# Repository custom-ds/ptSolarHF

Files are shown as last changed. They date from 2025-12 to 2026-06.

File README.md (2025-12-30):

# ptSolarHF
The ptSolar is the newest version of Project: Traveler's series of APRS trackers. The ptSolar has been designed and optimized for low-power operation, especially when using a solar panel.

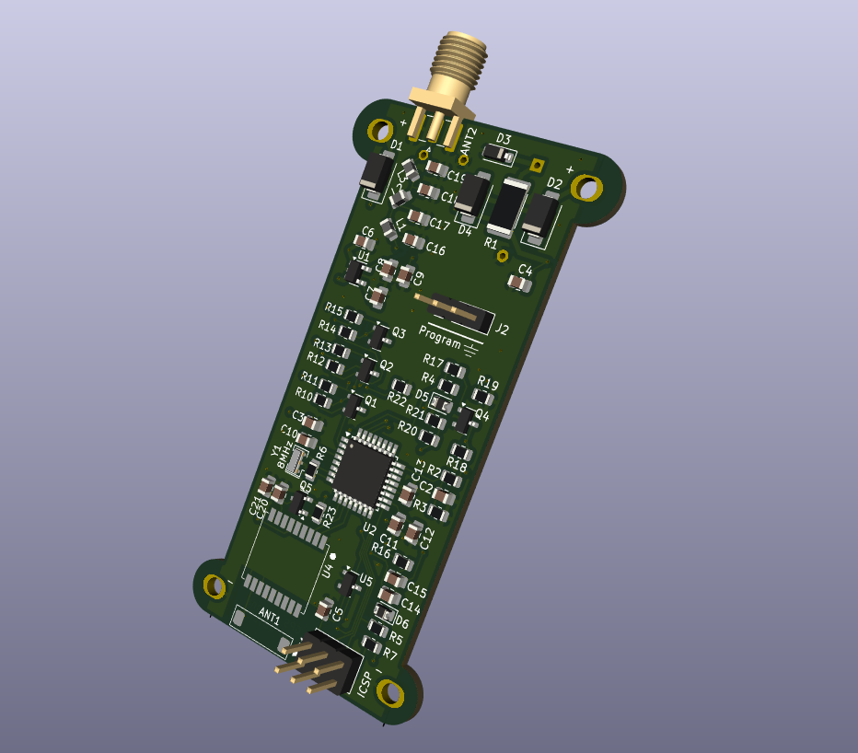
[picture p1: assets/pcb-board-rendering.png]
3D rendering of the ptSolar circuit board.


Under the hood, the ptSolar runs on the same __Microchip ATMega328p__ microcontroller that the other trackers have been using for years, although this board runs at a lower 3.3 volt level, and a slower 8MHz clock speed.

A 2m VHF transmitter is provided by the __SA818S-V__ transmitter-on-a-chip system, which means it's frequency agile and can be used throughout the world.

The GPS receiver is utilizes the __ATGM336H__ GPS engine which has a light-weight footprint while being a cost-effective solution. The ATGM336H is capable of position reports in excess of 60,000', making it a suitable solution for high altitude (latex) balloons traveling to over 100,000'.

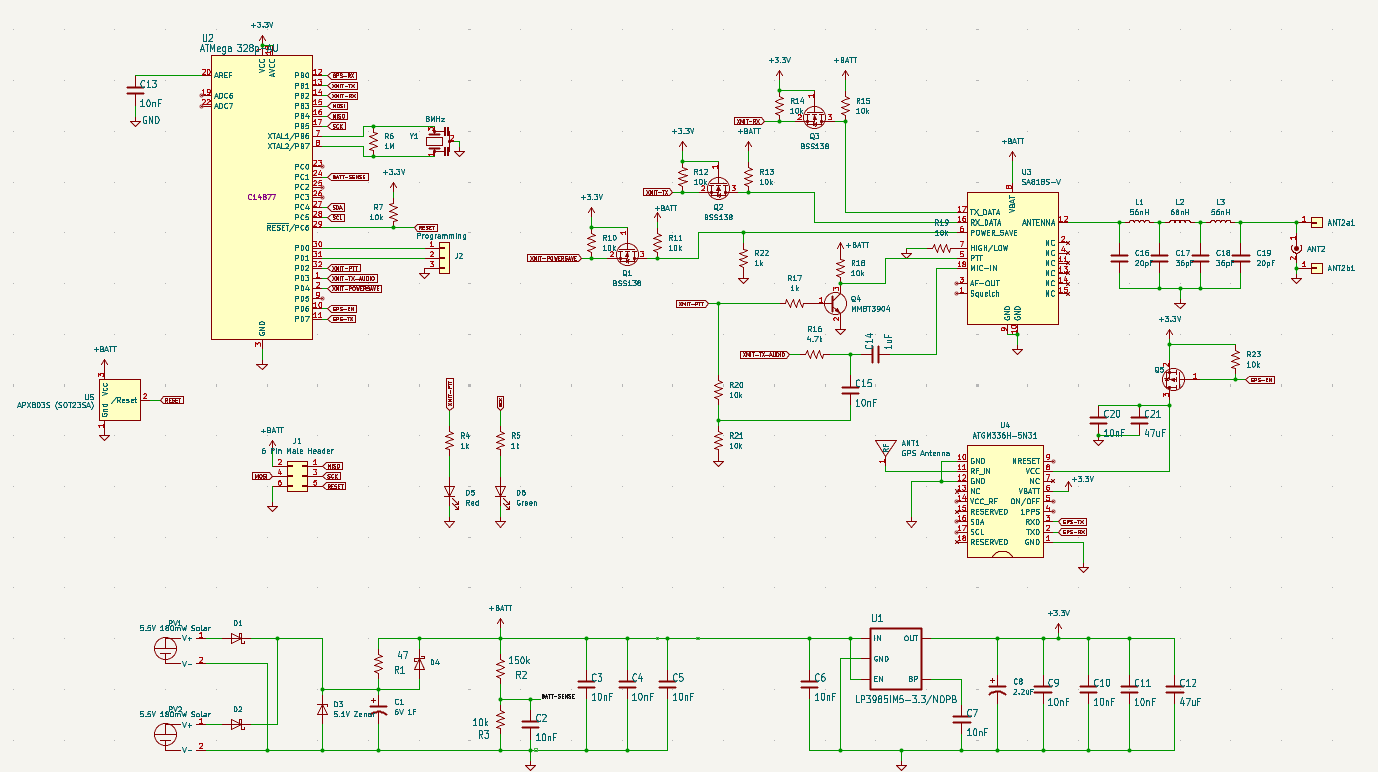
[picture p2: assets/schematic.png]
ptSolar schematic diagram.


## The Circuit Board
The circuit board is designed in Kicad and features a 4-layer design with castellated solder points for the attached solar panels.

The ptSolar is currently in the prototyping stages. Version 1.1.0 of the PCB was the initial design that was first built in early 2025, and includes the ATMega328p microcontroller, an ATGM336H GPS receiver, and the SA818S-V VHF transmitter. VHF signal filtering is provided by a 3-pole pi filter, reducing spurious harmonic output to well within Part 97 specifications.

## The Breakout Board
A Breakout board has been developed that can be temporarily or permanently paired to the top of the ptSolar tracker. The breakout includes a second ISCP programming port, a second serial data interface for configuring the tracker, a Sparkfun Qwiic connector for interfacing with other I2C sensors.

There is also a 2.1mm barrel jack for accepting power from a battery pack, along with the required 5V regulator when operating at higher supplied voltages. 

The Breakout Board mates to the tracker with a female .1" header connecting into the 6-pin (ISCP) and 8-pin (Serial, I2C) plugs on the ptSolar.

## Preparing the IDE for the Firmware
In the Arduino IDE and go to File &rarr; Preferences.  In the Additional Boards Manager URLs field, add the URL to the Project: Traveler website .json file:

```
https://www.projecttraveler.org/downloads/package_projecttraveler_index.json
```

Note that if there's already something in that field, you can click the small icon to the right of the text field where you are allowed to enter multiple entries on multiple lines.

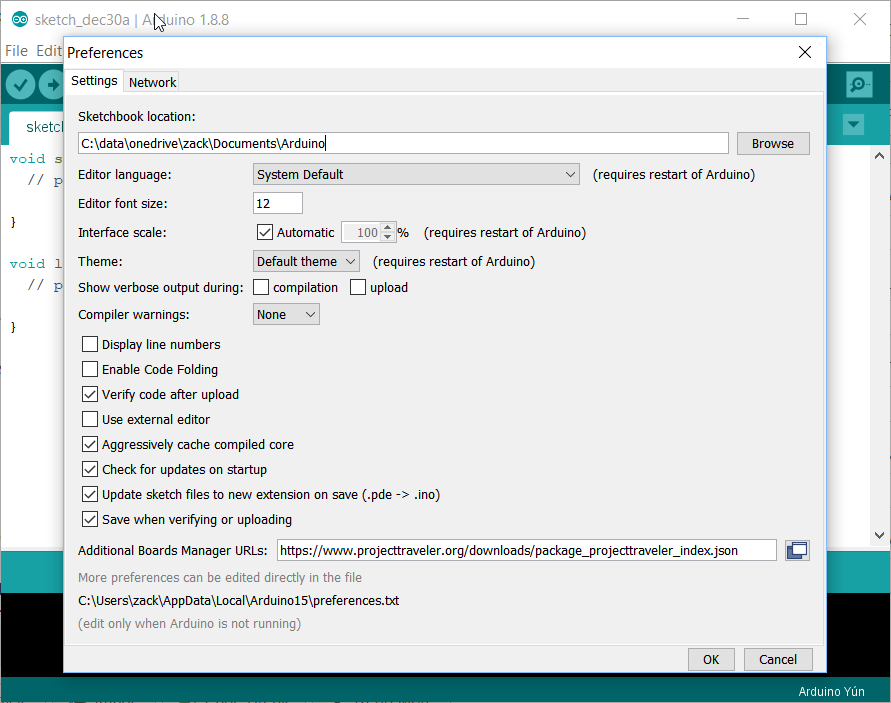
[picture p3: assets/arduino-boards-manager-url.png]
Setting the custom download URL for the Boards Manager.


Click OK to close the preferences dialog.  Then go to Tools &rarr; Boards &rarr; Boards Manager.

When the Boards Manager opens, select "Contributed" from the Type drop-down.  In the resulting list, you should find the Project Traveler Boards by Project Traveler option.  Click the Install button in the lower-right corner.

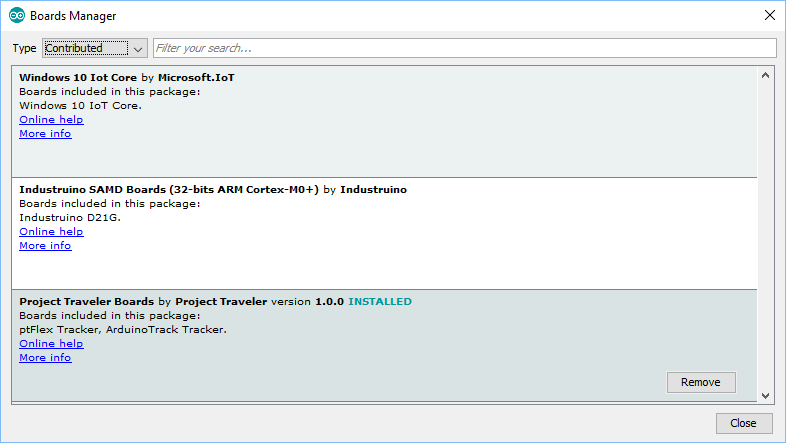
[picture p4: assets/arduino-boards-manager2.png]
Using the Boards Manager in Arduino IDE.


Close out of the Boards Manager dialog, and the back under Tools &rarr; Board, you should see "ptSolar Tracker (Arduino as ISP)" near the bottom of the list. 

## Setting the Controller Flags
If this is a brand new ptSolar board that has never been programmed before, there are several commands that must be run from a DOS command prompt. If the ptSolar was purchased as an assembled and tested kit, you can skip these steps.

The fuses are to be set as follows:
* Low: 0xFF
* High: 0xD6
* Extended: 0xFD

To program the fuses using the AVRDude tool (which is included in the Arduino IDE, and works with the Arduino As ISP programmer), open a command prompt on the PC.

```
C:\> cd \Program Files (x86)\Arduino\hardware\tools\avr\bin
C:\...> avrdude.exe -p m328p -b 19200 -c avrisp -C ..\etc\avrdude.conf -P comX* -U lfuse:w:0xDF:m -U hfuse:w:0xD6:m -U efuse:w:0xFD:m
```
Depending on your installation of the Arduino IDE, your avrdude may also be found in:

```
C:\Users\{Username}\AppData\Local\Arduino15\packages\arduino\tools\avrdude\6.3.0-arduino17\bin
```

This will write the fuses to the new processor.  To verify that the fuses have been written, run these commands:

```
avrdude.exe -p m328p -b 19200 -c avrisp -C ..\etc\avrdude.conf -P comX* -U lfuse:w:0xFF:m -U hfuse:w:0xD6:m -U efuse:w:0xFD:m 
```

\* Replace "comX" with whatever Com port your ArduinoISP is enumerating on.

### Verifying the Fuses
```
C:\...> avrdude.exe -p m328p -b 19200 -c avrisp -C ..\etc\avrdude.conf -P comX* -U lfuse:r:lowfuse:h -U hfuse:r:highfuse:h -U efuse:r:exfuse:h
C:\...> type lowfuse
C:\...> type highfuse
C:\...> type exfuse
```

\* Replace "comX" with whatever Com port your ArduinoISP is enumerating on.

## Loading the Firmware
To program the ptSolar, open the firmware Sketch in this GitHub Repository in the Arduino IDE. 

Go to the Tools &rarr; Board menu, select the "ptSolar Tracker (Arduino as ISP)" from the list of targets.  

The ptSolar boards are automatically configured to use the Arduino as ISP programmer to load the firmware onto the tracker boards, so no further configuration is necessary. Click the Upload button which will cause the Sketch to compile and will program to the ATmega328 processor similarly to how a normal Arduino board is programmed.

Sometimes it is necessary to apply external power to the ptSolar Tracker, depending on how much current the Programmer board is capable of sourcing.

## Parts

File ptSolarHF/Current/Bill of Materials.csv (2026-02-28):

Reference | Value | Datasheet | Footprint | Qty | DNP | Digikey | LCSC
ANT1 | GPS Antenna |  | Custom DS:Pulse ANT8010LL05R1575A Antenna | 1 |  | 553-ANT8010LL05R1575ACT-ND | C3284202
ANT2 | SMA Edge Mount (Optional) | ~ | Connector_Coaxial:SMA_Samtec_SMA-J-P-H-ST-EM1_EdgeMount | 1 |  | CON-SMA-EDGE-S-ND
C1 | 6V 0.5F | ~ | Custom DS:CDS CSP Super Cap 8mm dia | 1 |  | 4688-CSP-6R0L504R-TW-ND
C2,C3,C4,C5,C6,C7,C9,C10,C11,C13,C14,C20 | 10nF | ~ | Capacitor_SMD:C_0805_2012Metric | 12 |  | 399-1158-1-ND | C83170
C8 | 2.2uF | ~ | Capacitor_SMD:C_0805_2012Metric | 1 |  | 445-1420-1-ND | C107128
C12,C21 | 47uF | ~ | Capacitor_SMD:C_0805_2012Metric | 2 |  | 399-C0805C476M9PACTUCT-ND | C16780
C15 | 100nF | ~ | Capacitor_SMD:C_0805_2012Metric | 1 |  | 399-C0805C104K5RACTUCT-ND | C49678
C16,C19 | 180pF | ~ | Capacitor_SMD:C_0805_2012Metric | 2 |  | 490-11541-1-ND | C113826
C17,C18 | 270pF | ~ | Capacitor_SMD:C_0805_2012Metric | 2 |  | 490-9738-1-ND | C527183
D1,D2,D4 | CDBA340L-G Schottky | ~ | Diode_SMD:D_SMA | 3 |  | 641-1258-1-ND | C22364900
D3 | 5.1V Zenor | ~ | Diode_SMD:D_SOD-123 | 1 |  | MMSZ5231B-FDICT-ND | C85181
D5 | Red | ~ | Diode_SMD:D_0805_2012Metric | 1 |  | LTST-C171KRKT | C2295
D6 | Green | ~ | Diode_SMD:D_0805_2012Metric | 1 |  | LTST-C171GKT | C2297
J1 | 6 Pin Male Header | ~ | Connector_PinHeader_2.54mm:PinHeader_2x03_P2.54mm_Vertical | 1 |  | 732-5394-ND
J2 | Programming | ~ | Connector_PinHeader_2.54mm:PinHeader_1x03_P2.54mm_Vertical | 1 |  | 732-5316-ND
L1,L3 | 330nH | ~ | Inductor_SMD:L_0805_2012Metric | 2 |  | 490-5672-1-ND | C184530
L2 | 390nH | ~ | Inductor_SMD:L_0805_2012Metric | 1 |  | 490-5673-1-ND | C108076
PV1,PV2 | 5.5V 180mW Solar | https://www.powerfilmsolar.com/hubfs/documents/spec%20sheets/electronic%20component%20solar%20panels/electronic%20component%20solar%20panels%20spec%20sheet_cl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 | Custom DS:PowerFilm MPT3.6-75 | 2 |  | 1996-1020-ND
Q5 | DMP2004K-7 |  | Package_TO_SOT_SMD:SOT-23 | 1 |  | DMP2004KDICT-ND | C332297
R1 | 47 | ~ | Resistor_SMD:R_2512_6332Metric | 1 |  | YAG3404CT-ND | C513678
R2 | 150k | ~ | Resistor_SMD:R_0805_2012Metric | 1 |  | 311-150KCRCT-ND | C114558
R3,R7,R10,R11 | 10k | ~ | Resistor_SMD:R_0805_2012Metric | 4 |  | 13-RT0805FRD0710KLCT-ND | C100047
R4,R5 | 1k | ~ | Resistor_SMD:R_0805_2012Metric | 2 |  | 311-1.0KARCT-ND | C95781
R6 | 1M | ~ | Resistor_SMD:R_0805_2012Metric | 1 |  | 311-1.0MARCT-ND | C107700
R8,R9 | 4.7k | ~ | Resistor_SMD:R_0805_2012Metric | 2 |  | 311-4.7KARCT-ND | C60816
U1 | LP3985IM5-3.3/NOPB | https://www.ti.com/lit/ds/symlink/lp3985.pdf?HQS=dis-dk-null-digikeymode-dsf-pf-null-wwe&ts=1737860010554 | Package_TO_SOT_SMD:SOT-23-5 | 1 |  | LP3985IM5-3.3/NOPBCT-ND | C108877
U2 | ATMega 328p-AU | https://ww1.microchip.com/downloads/en/DeviceDoc/Atmel-7810-Automotive-Microcontrollers-ATmega328P_Datasheet.pdf | Package_QFP:TQFP-32_7x7mm_P0.8mm | 1 |  | ATMEGA328P-AU-ND | C14877
U3 | Si5351A-B-GT | https://www.silabs.com/documents/public/data-sheets/Si5351-B.pdf | Package_SO:MSOP-10_3x3mm_P0.5mm | 1 |  | 336-2399-5-ND | C504891
U4 | ATGM336H-5N31 | https://www.tinytronics.nl/product_files/002176_ATGM336H.pdf | Custom DS:ATGM336H-5N31 | 1 |  | ALIEXPRESS | C90770
U5 | APX803S (SOT23SA) |  | Package_TO_SOT_SMD:SOT-23 | 1 |  | APX803S-31SA-7DICT-ND | C129757
Y1 | 8MHz | ~ | Crystal:Resonator_SMD_Murata_CSTxExxV-3Pin_3.0x1.1mm | 1 |  | 490-CSTNE8M00G520000R0CT-ND | C907975
Y2 | 27MHz Xtal - 7M-27.000MEEQ-T | ~ | Crystal:Crystal_SMD_3225-4Pin_3.2x2.5mm | 1 |  | 887-1328-1-ND | C2450429

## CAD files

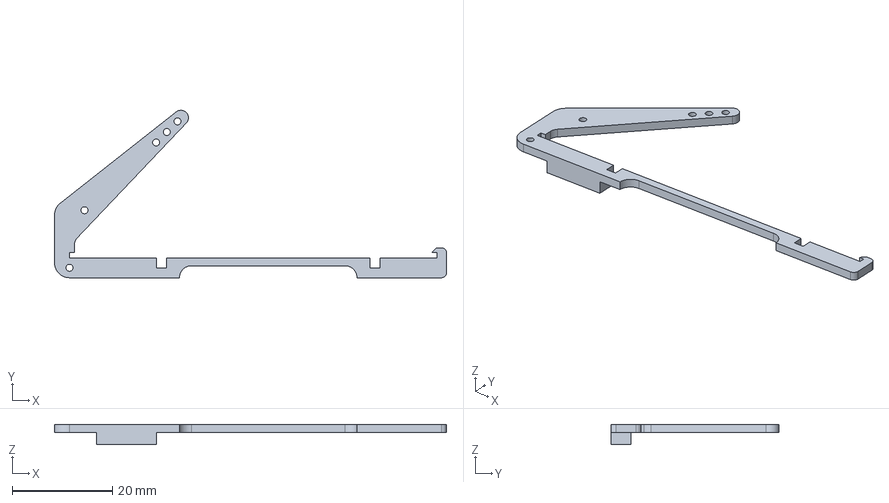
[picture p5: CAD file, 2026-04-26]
3d-prints/Angled Carrier.FCStd
78.4 x 33.5 x 4.00 mm

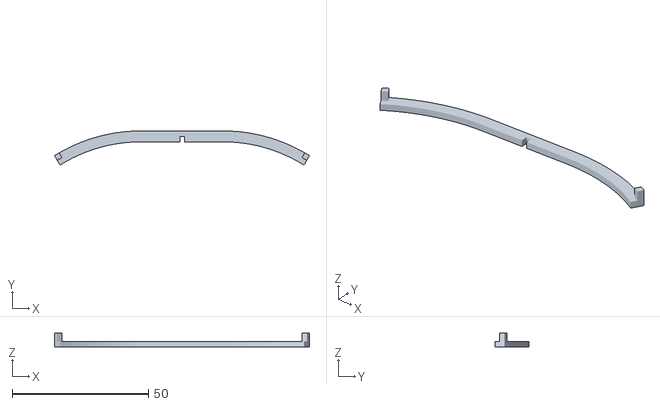
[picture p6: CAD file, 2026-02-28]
3d-prints/Rib.stl
93.5 x 12.5 x 5.00

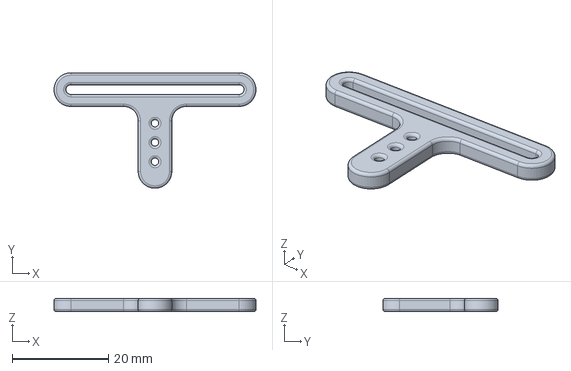
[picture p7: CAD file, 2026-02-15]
3d-prints/Balloon Neck Hanger.FCStd
42.0 x 24.0 x 2.80 mm

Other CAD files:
3d-prints/Spar.stl
3d-prints/Balloon Neck Hanger.stl

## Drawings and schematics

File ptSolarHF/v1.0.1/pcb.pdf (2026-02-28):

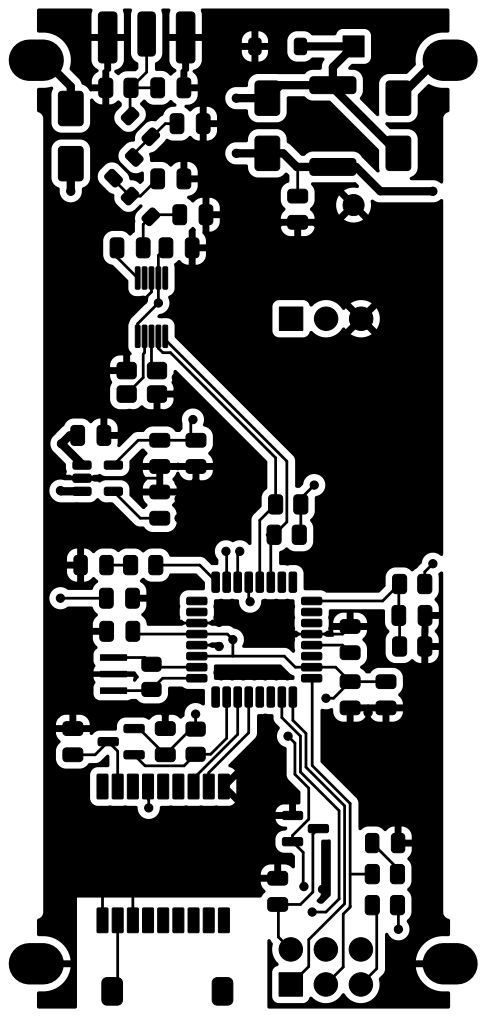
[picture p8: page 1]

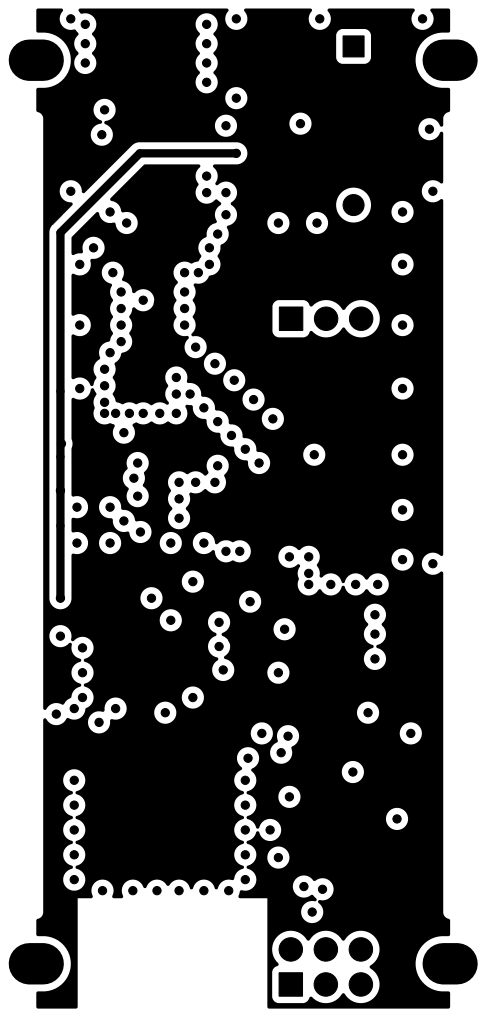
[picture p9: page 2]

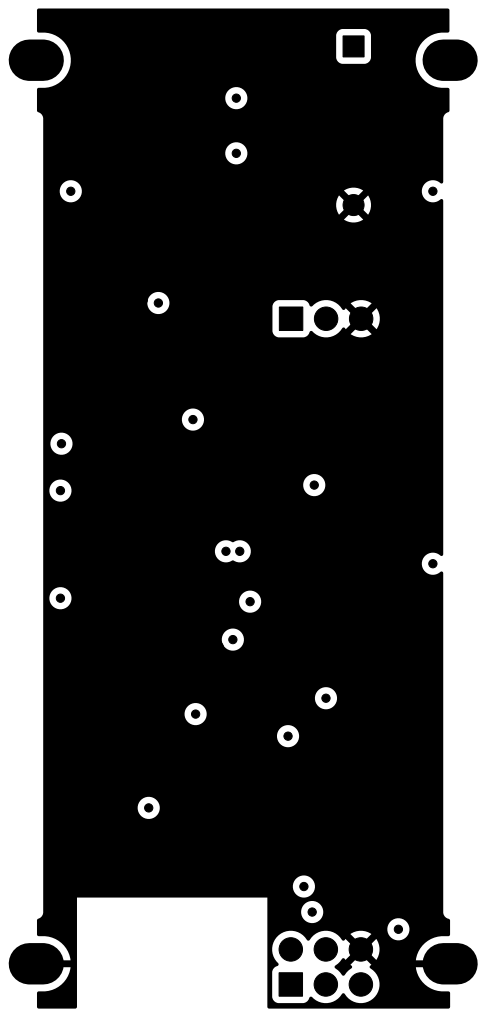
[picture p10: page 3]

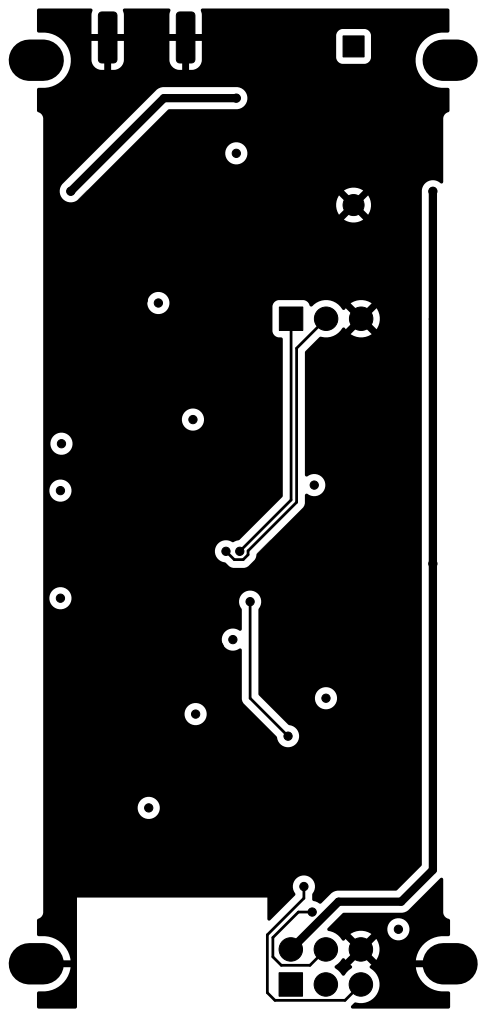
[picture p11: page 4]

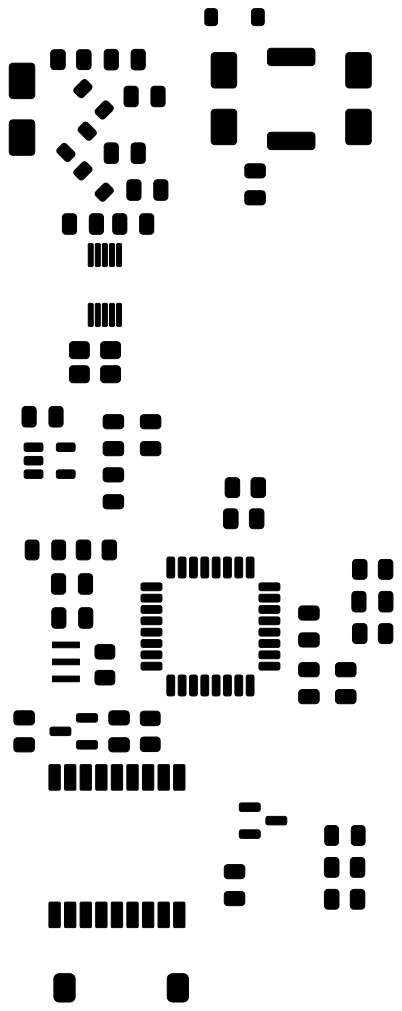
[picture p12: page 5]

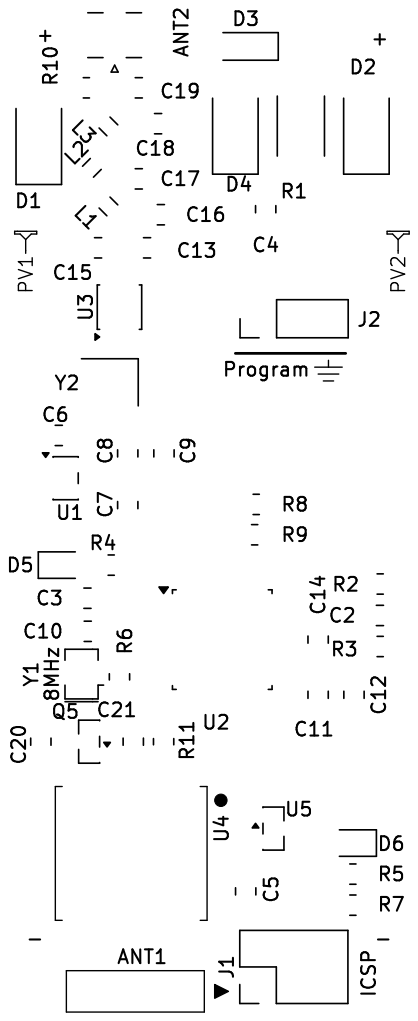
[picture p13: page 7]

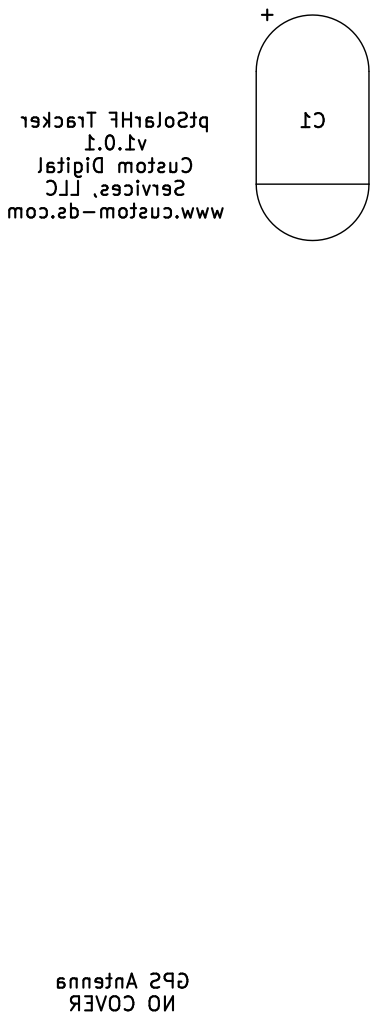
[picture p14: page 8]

LLC Services, www.custom-ds.com

Antenna GPS COVER NO

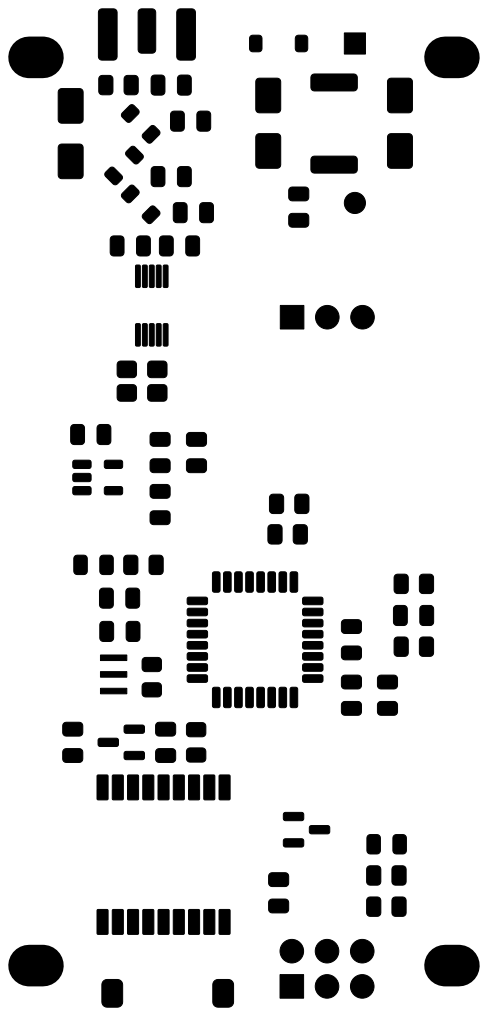
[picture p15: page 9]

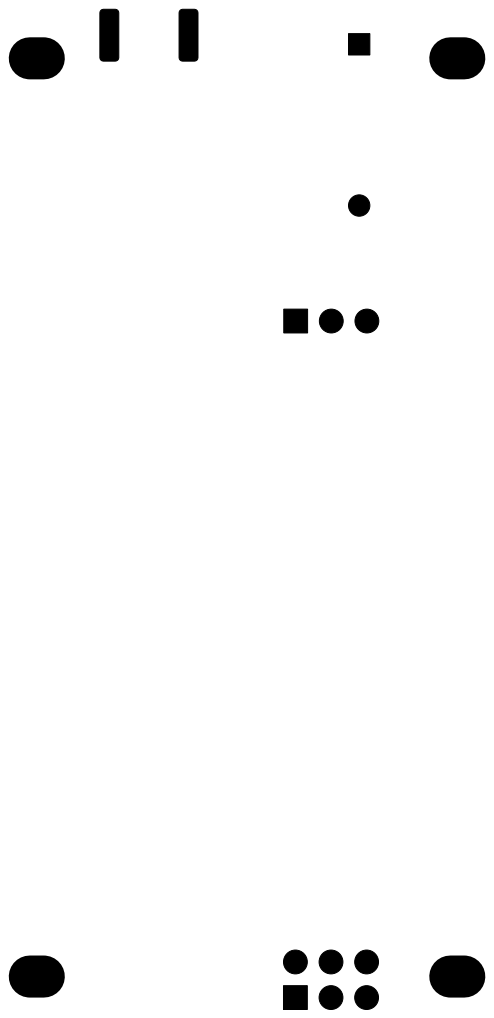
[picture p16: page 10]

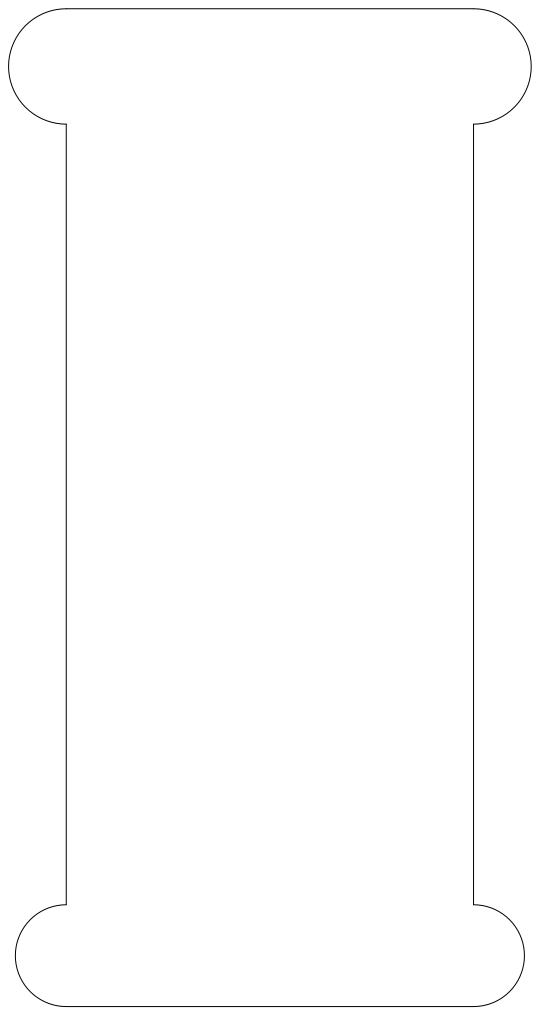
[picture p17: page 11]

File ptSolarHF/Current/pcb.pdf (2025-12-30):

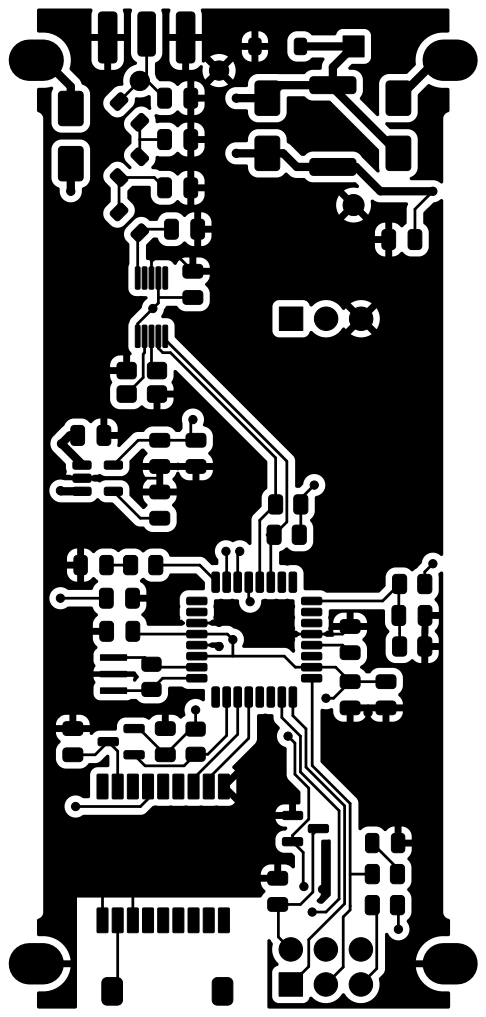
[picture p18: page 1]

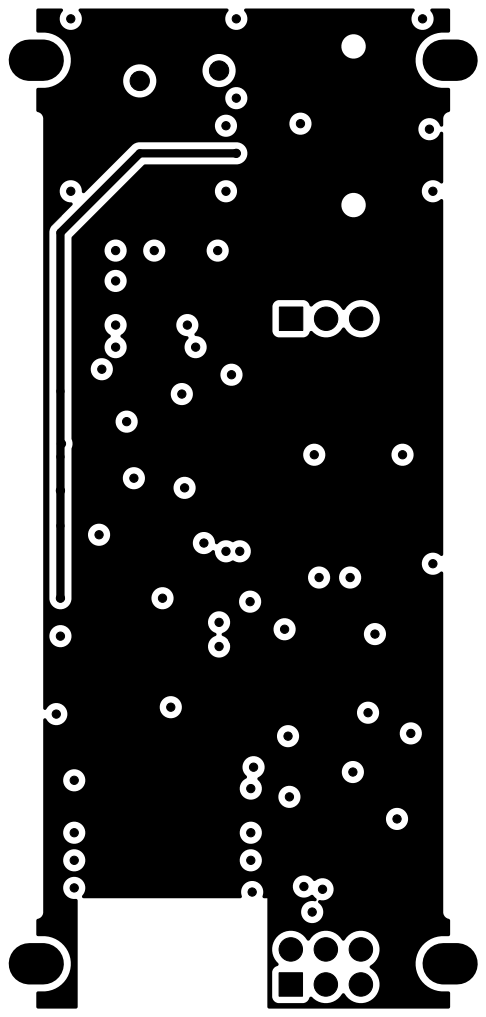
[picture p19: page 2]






LLC Services, www.custom-ds.com

Antenna GPS COVER NO




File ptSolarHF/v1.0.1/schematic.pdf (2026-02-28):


MISO MOSI XMIT-TX GPS-RX

8MHz R6
SCK GPS-TX GPS-EN

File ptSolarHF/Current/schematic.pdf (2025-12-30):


XMIT-PTT XMIT-TX-AUDIO

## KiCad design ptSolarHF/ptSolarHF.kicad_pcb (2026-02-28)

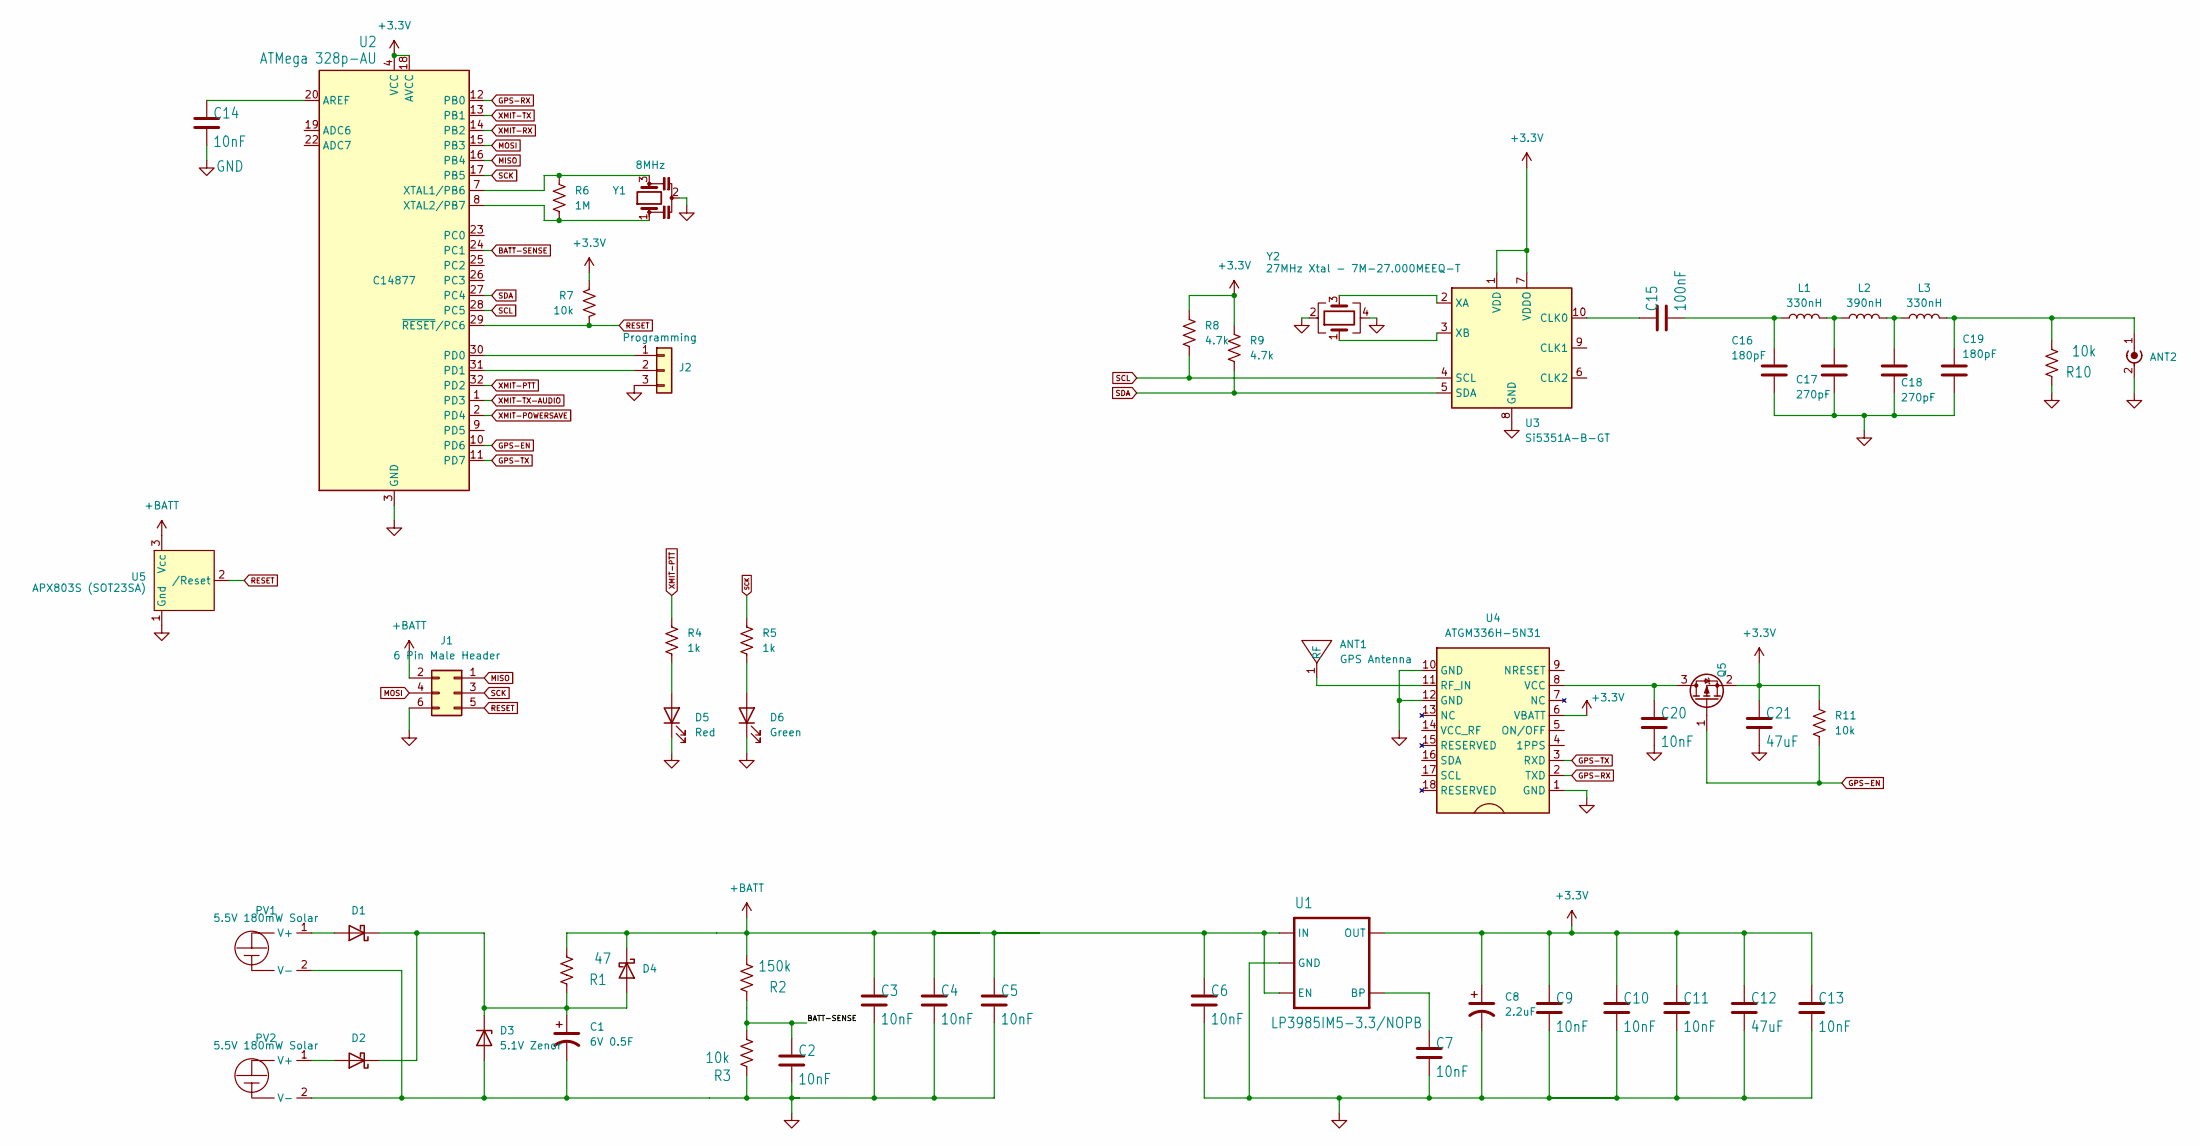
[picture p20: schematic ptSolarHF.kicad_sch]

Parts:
ANT1: GPS Antenna; Pulse ANT8010LL05R1575A Antenna; Digikey 553-ANT8010LL05R1575ACT-ND
ANT2: SMA Edge Mount (Optional); SMA_Samtec_SMA-J-P-H-ST-EM1_EdgeMount; Digikey CON-SMA-EDGE-S-ND
C1: 6V 0.5F; CDS CSP Super Cap 8mm dia; Digikey 4688-CSP-6R0L504R-TW-ND
C2, C3, C4, C5, C6, C7, C9, C10, C11, C13, C14, C20: 10nF; C_0805_2012Metric; Digikey 399-1158-1-ND
C8: 2.2uF; C_0805_2012Metric; Digikey 445-1420-1-ND
C12, C21: 47uF; C_0805_2012Metric; Digikey 399-C0805C476M9PACTUCT-ND
C15: 100nF; C_0805_2012Metric; Digikey 399-C0805C104K5RACTUCT-ND
C16, C19: 180pF; C_0805_2012Metric; Digikey 490-11541-1-ND
C17, C18: 270pF; C_0805_2012Metric; Digikey 490-9738-1-ND
D1, D2, D4: CDBA340L-G Schottky; D_SMA; Digikey 641-1258-1-ND
D3: 5.1V Zenor; D_SOD-123; Digikey MMSZ5231B-FDICT-ND
D5: Red; D_0805_2012Metric; Digikey LTST-C171KRKT
D6: Green; D_0805_2012Metric; Digikey LTST-C171GKT
J1: 6 Pin Male Header; PinHeader_2x03_P2.54mm_Vertical; Digikey 732-5394-ND
J2: Programming; PinHeader_1x03_P2.54mm_Vertical; Digikey 732-5316-ND
L1, L3: 330nH; L_0805_2012Metric; Digikey 490-5672-1-ND
L2: 390nH; L_0805_2012Metric; Digikey 490-5673-1-ND
PV1, PV2: 5.5V 180mW Solar; PowerFilm MPT3.6-75; Digikey 1996-1020-ND
Q5: DMP2004K-7; SOT-23; Digikey DMP2004KDICT-ND
R1: 47; R_2512_6332Metric; Digikey YAG3404CT-ND
R2: 150k; R_0805_2012Metric; Digikey 311-150KCRCT-ND
R3, R7, R10, R11: 10k; R_0805_2012Metric; Digikey 13-RT0805FRD0710KLCT-ND
R4, R5: 1k; R_0805_2012Metric; Digikey 311-1.0KARCT-ND
R6: 1M; R_0805_2012Metric; Digikey 311-1.0MARCT-ND
R8, R9: 4.7k; R_0805_2012Metric; Digikey 311-4.7KARCT-ND
U1: LP3985IM5-3.3/NOPB; SOT-23-5; Digikey LP3985IM5-3.3/NOPBCT-ND
U2: ATMega 328p-AU; TQFP-32_7x7mm_P0.8mm; Digikey ATMEGA328P-AU-ND
U3: Si5351A-B-GT; MSOP-10_3x3mm_P0.5mm; Digikey 336-2399-5-ND
U4: ATGM336H-5N31; Digikey ALIEXPRESS
U5: APX803S (SOT23SA); SOT-23; Digikey APX803S-31SA-7DICT-ND
Y1: 8MHz; Resonator_SMD_Murata_CSTxExxV-3Pin_3.0x1.1mm; Digikey 490-CSTNE8M00G520000R0CT-ND
Y2: 27MHz Xtal - 7M-27.000MEEQ-T; Crystal_SMD_3225-4Pin_3.2x2.5mm; Digikey 887-1328-1-ND

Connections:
+3.3V: C8.1, C9.1, C10.1, C11.1, C12.1, C13.1, C21.1, Q5.2 (S), R7.1, R8.1, R9.1, R11.1, U1.5 (OUT), U2.4 (VCC), U2.6 (VCC), U2.18 (AVCC), U3.1 (VDD), U3.7 (VDDO), U4.6 (VBATT)
+BATT: C3.1, C4.1, C5.1, C6.1, D4.1 (K), J1.2, R1.2, R2.2, U1.1 (IN), U1.3 (EN), U5.3 (Vcc)
BATT-SENSE: C2.1, R2.1, R3.2, U2.24 (PC1)
GND: ANT2.2 (Ext), C1.2, C2.2, C3.2, C4.2, C5.2, C6.2, C7.2, C8.2, C9.2, C10.2, C11.2, C12.2, C13.2, C14.2, C16.1, C17.1, C18.1, C19.1, C20.2, C21.2, D3.2 (A), D5.1 (K), D6.1 (K), J1.6, J2.3, PV1.2 (V-), PV2.2 (V-), R3.1, R10.1, U1.2 (GND), U2.3 (GND), U2.5 (GND), U2.21 (GND), U3.8 (GND), U4.1 (GND), U4.10 (GND), U4.12 (GND), U5.1 (Gnd), Y1.2, Y2.2, Y2.4
GPS-EN: Q5.1 (G), R11.2, U2.10 (PD6)
GPS-RX: U2.12 (PB0), U4.2 (TXD)
GPS-TX: U2.11 (PD7), U4.3 (RXD)
MISO: J1.1, U2.16 (PB4)
MOSI: J1.4, U2.15 (PB3)
unnamed: ANT1.1 (RF), U4.11 (RF_IN)
unnamed: ANT2.1 (In), C19.2, L3.2, R10.2
unnamed: C15.2, C16.2, L1.1
unnamed: C17.2, L1.2, L2.1
unnamed: C18.2, L2.2, L3.1
unnamed: D1.2 (A), PV1.1 (V+)
unnamed: C1.1, D1.1 (K), D2.1 (K), D3.1 (K), D4.2 (A), R1.1
unnamed: D2.2 (A), PV2.1 (V+)
unnamed: D5.2 (A), R4.2
unnamed: D6.2 (A), R5.2
unnamed: J2.1, U2.30 (PD0)
unnamed: J2.2, U2.31 (PD1)
unnamed: C20.1, Q5.3 (D), U4.8 (VCC)
unnamed: C7.1, U1.4 (BP)
unnamed: C14.1, U2.20 (AREF)
unnamed: R6.1, U2.7 (XTAL1/PB6), Y1.3
unnamed: R6.2, U2.8 (XTAL2/PB7), Y1.1
unnamed: C15.1, U3.10 (CLK0)
unnamed: U3.2 (XA), Y2.3
unnamed: U3.3 (XB), Y2.1
RESET: J1.5, R7.2, U2.29 (~RESET/PC6), U5.2 (/Reset)
SCK: J1.3, R5.1, U2.17 (PB5)
SCL: R8.2, U2.28 (PC5), U3.4 (SCL)
SDA: R9.2, U2.27 (PC4), U3.5 (SDA)
XMIT-POWERSAVE: U2.2 (PD4)
XMIT-PTT: R4.1, U2.32 (PD2)
XMIT-RX: U2.14 (PB2)
XMIT-TX: U2.13 (PB1)
XMIT-TX-AUDIO: U2.1 (PD3)

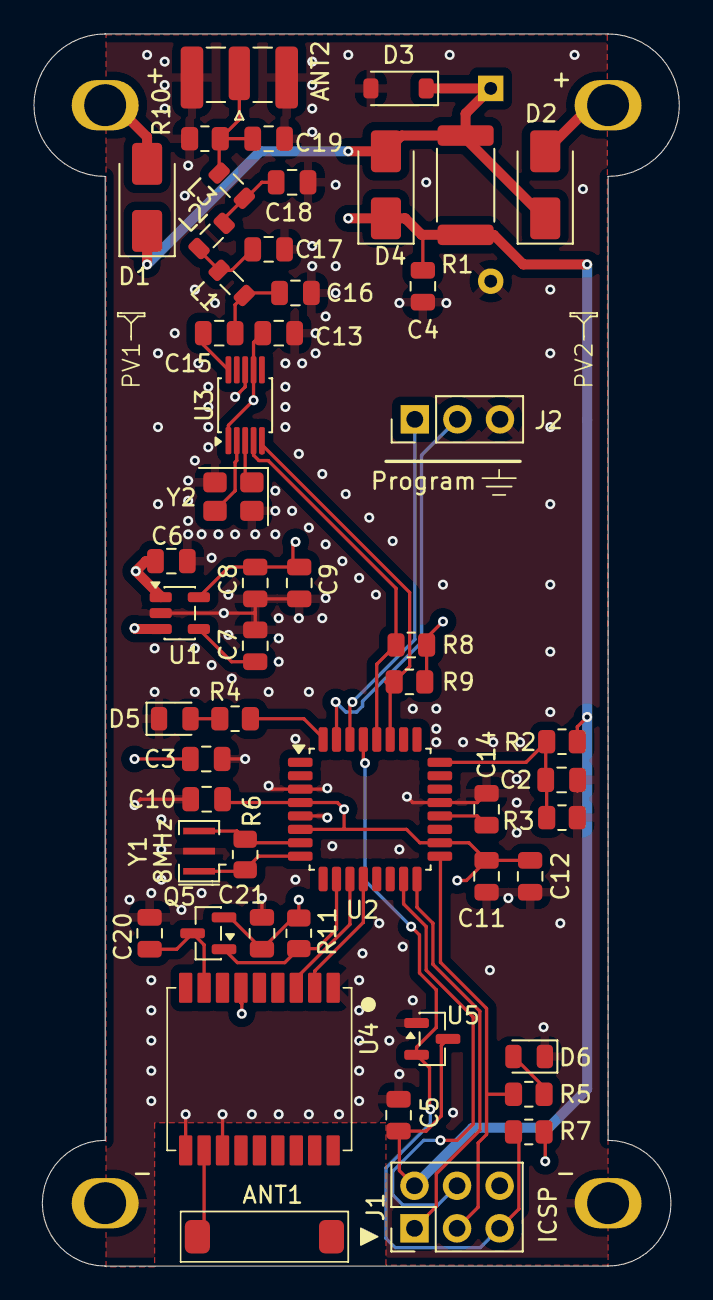
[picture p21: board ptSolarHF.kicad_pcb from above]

Board: 4 copper layers, 38.5 x 73.5 mm, 55 parts (1 on the bottom side), 34 nets.

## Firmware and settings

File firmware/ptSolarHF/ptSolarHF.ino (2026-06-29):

 /*
Project: Traveler ptSolarHF Firmware
Copyright 2011-2026 - Zack Clobes (W0ZC), Custom Digital Services, LLC


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
You should have received a copy of the GNU General Public License along with this program.  If not, see <http://www.gnu.org/licenses/>.


Before programming for the first time, the ATmega fuses must be set.
 Low:      0xDF
 High:     0xD6
 Extended: 0xFD


This firmware requires the following libraries to be installed with the Library Manager inside of the Arduino IDE:
  - Si5351 Library by Etherkit

*/


#define FIRMWARE_VERSION "1.0.3"
#define CONFIG_PROMPT "\n\n# "
#include "BoardDef.h"   //defines if this is a ptFlex, ptSolar, or ptSolarHF PCB board



#define __PROG_TYPES_COMPAT__
#include <avr/pgmspace.h>
#include <avr/wdt.h>
#include <si5351.h>
#include <string.h>
#include <Wire.h>

#include "wspr_enc.h"
#include "nhash.h"
#include "ptConfig.h"
#include "GPS.h"
#include "ptTracker.h"


//PD0 is Serial Port RX
//PD1 is Serial Port TX
#define PIN_PTT_OUT 2     //PD2
//PD3 is not used
//PD4 is not used
#define PIN_AUDIO 5       //PD5   - Audio Annunciation
#define PIN_GPS_EN 6      //PD6
#define PIN_GPS_TX 7      //PD7

#define PIN_GPS_RX 8      //PB0
//PB1 is not used
//PB2 is not used
//PB3 is MOSI
//PB4 is MISO
#define PIN_LED 13        //PB5

//Analog Pins
//PC0 is not used
#define PIN_ANALOG_BATTERY A1   //PC1
//PC2 is not used
//PC3 is not used
//PC4 is SDA
//PC5 is SCL
//PC6 is reset and not available


//Debugging options
#define CONFIG_TIMEOUT 600000

#define WSPR_TONE_SPACING_CENTI_HZ 146
#define WSPR_SYMBOL_COUNT 162
#define WSPR_TONE_MS 683


Si5351 si5351;
static uint8_t wspr_symbols[WSPR_SYMBOL_COUNT];
ptConfig Config;                                                                        //Configuration object
ptTracker Tracker(PIN_LED, PIN_AUDIO, PIN_ANALOG_BATTERY, Config.getAnnounceMode());    //Object that manages the board-specific functions
GPS GPSParser(PIN_GPS_RX, PIN_GPS_TX, PIN_GPS_EN);                                      //Object that parses the GPS strings

//Keep track of the grid square and altitude between transmissions
uint8_t coarseAlt, fineAlt;
char szGrid[7];

enum XmitState{
    NO_XMIT,
    XMIT_TYPE1,
    XMIT_TYPE2,
    XMIT_TYPE3
};
XmitState xmitState = NO_XMIT;
XmitState nextXmitState = NO_XMIT;

/**
 * @brief  The function that runs first before the main loop() function is called indefinitely.
 * @note   This function is called once at startup and is used to initialize the board and set up the hardware.
 */
void setup() {
    Serial.begin(19200);

    pinMode(PIN_PTT_OUT, OUTPUT);
    digitalWrite(PIN_PTT_OUT, LOW);    //Set PTT to low (not transmitting)

    wdt_disable();    //disable the watchdog timer by default
    wdt_enable(WDTO_8S);    //Enable the Watchdog if configured

    wdt_reset();    //reset the watchdog timer (even if we're not using it)
    showVersion();    //show the version of the firmware that we're running

    Tracker.annunciate('k');

    wdt_reset();

    Serial.println(F("Init Si5351"));
    si5351.init(SI5351_CRYSTAL_LOAD_10PF, 27000000, 0);
    si5351.set_correction(Config.getCorrection(), SI5351_PLL_INPUT_XO);
    si5351.drive_strength(SI5351_CLK0, SI5351_DRIVE_8MA);
    si5351.output_enable(SI5351_CLK0, 0);       //Turn off any outputs for now

    GPSParser.setDebugNEMA(true);    ///TODO: Need to pull this from Configuration
    GPSParser.setDebugLevel(1);    //Get full verbose output from the GPS

    //GPSParser.testWSPRAltitude();    //Test the WSPR altitude calculation function with some known values to make sure it's working correctly
}


/**
 * @brief  Main loop for the program.  This is where the main logic of the program is executed.
 * @note   This function will run continuously until the board is powered off or reset.
 */
void loop()
{

  static unsigned long battMillivolts;
  static uint8_t iSeconds, iMinutes, iHours;
  static byte byTemp;
  static bool bUseFreq1 = true; // Used to alternate between the two frequencies if configured to do so

  wdt_reset();

  // Check to see if we have a command from the serial port to indicate that we need to enter config mode
  if (Serial.available())
  {
    byTemp = Serial.read();
    if (byTemp == '!')
    {
      doConfigMode();
    }
  }

  Serial.println("");
  Serial.println("");
  for (int i = 0; i < 40; i++)
    Serial.print("=");
  Serial.println("");

  // Reboot the system hourly if configured to do so
  if (Config.getRebootHourly())
  {
    // Reboot if we've been running for 60 minutes
    if (millis() > 3600000)
    {
      // we've been running for 60 minutes - reboot the system
      Serial.println(F("60min Reboot"));
      delay(1000);
      Tracker.reboot();
    }
  }

  battMillivolts = (unsigned long)(Tracker.readBatteryVoltage(true) * 1000); // read the battery voltage and spit it out to the serial port

  // check to see if we have sufficient battery to run the GPS
  if (battMillivolts >= Config.getVoltThreshGPS())
  {
    GPSParser.enableGPS(true); // enable the GPS module if it's not already. If it wasn't enabled, this will also initialize it.
    GPSParser.collectGPSStrings();
  }
  else
  {
    // See if the Battery has dropped 100mV below the threshold.  If so, disable the GPS until the battery comes back up
    if (battMillivolts < (Config.getVoltThreshGPS() - 100))
    {
      // we don't have enough battery to run the GPS - disable it
      Serial.println(F("Disable GPS"));
      GPSParser.disableGPS();
    }
    Serial.println(F("Low Batt, no GPS"));
    delay(750); // wait for about the amount of time that we'd normally spend grabbing a GPS reading
  }

  xmitState = NO_XMIT; // Need to assume we're not transmitting even if it was skipped last time around. Otherwise it may transmit beyond top of the minute.
  GPSParser.getGPSTime(&iHours, &iMinutes, &iSeconds);
  if (iSeconds <= 2 && iMinutes % 2 == 0)
  {
    Serial.println(F("TOM")); // Top of minute

    if (nextXmitState != NO_XMIT)
    {
      // We have a pending transmit state from the last time we checked - use that instead
      xmitState = nextXmitState;
      nextXmitState = NO_XMIT;
      // No need to get the Grid/altitude since it was already captures when sending the Type2.
      Serial.println(F("Xmit next"));
    }
    else
    {

      // preload the position and altitude so that we don't have to worry about the GPS loosing lock during transmissions
      GPSParser.getWSPRAltitude(coarseAlt, fineAlt);
      GPSParser.getGridSquare(szGrid, 6);

      if ((!GPSParser.FixQuality() || GPSParser.NumSats() < 4) || GPSParser.isRFBlackoutZone())
      {
        if (GPSParser.isRFBlackoutZone())
        {
          Serial.print(F("Blackout"));
        }
        else
        {
          Serial.print(F("GPS"));
        }
        Serial.println(F("-No Xmit"));
        wdt_reset();
      }
      else
      {
        //We weren't set to transmit a Type 3 message, and we're not in a blackout zone, and we have a valid GPS lock - see if it's time to transmit
        
        if ((iMinutes + Config.getTxModOffset()) % Config.getTxMod() == 0)
        {
          Serial.print(F("Xmit "));
          // It's time to transmit on this cycle - see what we're configured to send
          if (Config.getWSPRMessageType() & 0x01)
          {
            // Type 1 message
            xmitState = XMIT_TYPE1;
            nextXmitState = NO_XMIT;

            Serial.println(F("1"));
          }
          else if (Config.getWSPRMessageType() & 0x02)
          {
            // Type 2/3 message
            xmitState = XMIT_TYPE2;
            nextXmitState = XMIT_TYPE3;

            Serial.println(F("2/3"));
          }
        }
      }
    }
  }

  if (xmitState != NO_XMIT)
  {

    // If there's still a valid transmit state, go ahead and build and send the WSPR packet
    if (xmitState == XMIT_TYPE1)
    {
      buildWSPRSymbols(1);
      sendWSPR(bUseFreq1);

      if (Config.getWSPRMessageType() & 0x80)
        bUseFreq1 = !bUseFreq1; // Alternate frequencies between packets
      else
        bUseFreq1 = true; // Always use the primary frequency if we're not configured to alternate
    }
    else if (xmitState == XMIT_TYPE2)
    {
      buildWSPRSymbols(2);
      sendWSPR(bUseFreq1);

      // don't need to alternate after the type 2. Wait for the type 3
    }
    else if (xmitState == XMIT_TYPE3)
    {
      buildWSPRSymbols(3);
      sendWSPR(bUseFreq1);

      if (Config.getWSPRMessageType() & 0x80)
        bUseFreq1 = !bUseFreq1; // Alternate frequencies between packets
      else
        bUseFreq1 = true; // Always use the primary frequency if we're not configured to alternate
    }

    xmitState = NO_XMIT; // we're done transmitting - reset
  }
}

/**
 * @brief   Constructs the WSPR symbols (packet) to be transmitted based on the current GPS data and configuration.
 * @note    Once the symbols are built, they are stored in the global wspr_symbols array.
 */
static void buildWSPRSymbols(uint8_t msgType) {
    char szAltitude[4];
    char szCallsign[11];      //WSPR supports 10 digit callsigns
    char cGridFithDigit = '\0';

    wdt_reset();

    Serial.print(F("WSPR "));
    Serial.println(msgType);
    //Calculate the coarse altitude for WSPR encoding
    itoa(coarseAlt, szAltitude, 10);

    Config.getCallsign(szCallsign, sizeof(szCallsign));

    //Message type gets infered from the following logic:
    // Type 1 - If a standard 4-character grid square is used and a "normal" callsign which is <= 6 characters and no slashes
    // Type 2 - If a standard 4-character grid square is used and a "special" callsign which is > 6 characters or has a slash
    // Type 3 - If a 6-character grid square is used
    //
    // Convention states that a type 2 and type 3 message should be used together to convey more information. If both packets aren't sent
    //  together WSPRNet.org won't display them correctly, and will use the prior six-digit grid square with a newer Type 2 location.


    
    Serial.print(F("Cal "));
    Serial.println(szCallsign);
    Serial.print(F("Grd "));
    Serial.println(szGrid);
    Serial.print(F("Alt "));
    Serial.println(szAltitude);


    //Build the WSPR symbols
    if (msgType < 3)
    {
      //Convert this into a 4 digit grid square
      cGridFithDigit = szGrid[4];
      szGrid[4] = '\0';
      wspr_enc(szCallsign, szGrid, szAltitude, wspr_symbols); 

      //replace the fifth digit
      szGrid[4] = cGridFithDigit;
    } 
    else 
    {
       wspr_enc(szCallsign, szGrid, szAltitude, wspr_symbols);
    }
}


/**
 * @brief   Transmits the WSPR symbols that were previously built using the Si5351 clock generator.
 * @note    This function will transmit the WSPR symbols stored in the global wspr_symbols array. It takes about 111 seconds to transmit the entire packet.
 */
static void sendWSPR(bool useFreq1) {
    if (Config.getFineAltitudeModulation()) {
      if (fineAlt > 200) fineAlt = 100;
    } else {
      fineAlt = 0;    // If we're not using fine altitude modulation, set the fine altitude to zero so that it doesn't affect the tone frequencies  
    }
    const uint64_t base_cHz = (uint64_t)((useFreq1 ? Config.getFrequencyTx1() : Config.getFrequencyTx2()) + Config.getToneOffset() + fineAlt) * 100ULL;
    byte byTemp;
    Serial.print(F("Xmit "));
    Serial.println((useFreq1 ? "freq 1" : "freq 2"));

    GPSParser.disableGPS(); // turn off the GPS while we're transmitting.

    //make sure the correction has been set before we transmit
    si5351.set_correction(Config.getCorrection(), SI5351_PLL_INPUT_XO);
    si5351.output_enable(SI5351_CLK0, 1);
    digitalWrite(PIN_PTT_OUT, HIGH);

    for (uint16_t i = 0; i < WSPR_SYMBOL_COUNT; i++)
    {
        wdt_reset();
        const uint8_t sym = wspr_symbols[i] & 0x03;
        const uint64_t f_cHz = base_cHz + (uint64_t)sym * (uint64_t)WSPR_TONE_SPACING_CENTI_HZ;
        si5351.set_freq(f_cHz, SI5351_CLK0);

        //Check if we're trying to interrupt the transmission to enter config mode
        if (Serial.available())
        {
            byTemp = Serial.read();
            if (byTemp == '!') 
            {
                //Shut the transmitter down
                si5351.output_enable(SI5351_CLK0, 0);
                digitalWrite(PIN_PTT_OUT, LOW);

                //Go into config mode
                doConfigMode();
            }
        }
        delay(WSPR_TONE_MS);
    }

    si5351.output_enable(SI5351_CLK0, 0);
    digitalWrite(PIN_PTT_OUT, LOW);
    
    //The GPS will turn back on at the top of the loop(), assuming the battery voltage is sufficient, so we don't need to turn it back on here.

    Serial.println(F("Done"));
}


/**
 * @brief showVersion - Displays the version of the firmware and configuration
 * @return void
 */
void showVersion() {
  Serial.println(F("ptSolarHF Tracker"));
  Serial.print(F("Firmware Version: "));
  Serial.println((char *)FIRMWARE_VERSION);
  Serial.print(F("Config Version: "));
  Serial.println(CONFIG_VERSION);
  Serial.flush();
}


/**
 * @brief doConfigMode - This function is used to enter the configuration mode of the tracker. There are diagnostic routines, and the ability to read/write the EEPROM settings.
 * @return void
 */
void doConfigMode() {
  byte byTemp;

  showVersion();
  Serial.print(F(("Corr: ")));
  Serial.println(Config.getCorrection());
  Serial.print(CONFIG_PROMPT);

  delay(750);
  Tracker.annunciate('c');

  //keep track of how long we can listen to the GPS
  unsigned long ulUntil = millis() + CONFIG_TIMEOUT;
  
  while (millis() < ulUntil ) {
    //Endless loop. Only exit is to reboot with the 'Q', or after 10 minutes of inactivity
    wdt_reset();
    if (Serial.available()) {
      byTemp = Serial.read();


      if (byTemp == '!') {
        showVersion();
      }

      if (byTemp == '0') {
        //used to reset the tracker back to N0CALL defaults
        Serial.println(F("Defaults"));
        Config.setDefaultConfig();        
        Tracker.annunciate('w');
      }


      if (byTemp == 'E' || byTemp == 'e') {
        //exercise mode to check out all of the I/O ports
        
        Serial.println(F("Exercise"));
        
        Serial.println(F(" annun"));
        Config.setAnnounceMode(0x03);    //temporarily set the announce mode to both
        Tracker.annunciate('x');
        
        Serial.println(Tracker.readBatteryVoltage(true));
        GPSParser.collectGPSStrings();   //check the GPS  
      }

      if (byTemp == 'Q' || byTemp == 'q') {
        //Quit the config mode
        reboot();
      }

      if (byTemp == 'R' || byTemp == 'r') {
        Config.readEEPROM();    //pull the configs from eeprom
        Config.sendConfigToPC();

        reboot();    //reboot the system while we're waiting for a new config to be loaded
      }

      //Adjust the Correction factor
      if (byTemp == 'd') {
        //down by 100
        Config.setCorrection(Config.getCorrection() - 100);
        Config.writeEEPROM();   //store the change
      }
      if (byTemp == 'D') {
        //down by 1000
        Config.setCorrection(Config.getCorrection() - 1000);
        Config.writeEEPROM();   //store the change
      }
      if (byTemp == 'u') {
        //up by 100
        Config.setCorrection(Config.getCorrection() + 100);
        Config.writeEEPROM();   //store the change
      }
      if (byTemp == 'U') {
        //up by 1000
        Config.setCorrection(Config.getCorrection() + 1000);
        Config.writeEEPROM();   //store the change
      }
      if (byTemp == 'z' || byTemp == 'Z') {
        //reset to zero
        Config.setCorrection(0);
        Config.writeEEPROM();   //store the change
      }

      //Test the transmitter for frequency accuracy. Lower case 't' gives 5 seconds, upper case 'T' gives 30 seconds
      if (byTemp == 't' || byTemp == 'T') {
        si5351.set_correction(Config.getCorrection(), SI5351_PLL_INPUT_XO);
        si5351.set_freq(1000000000ULL, SI5351_CLK0);
        si5351.output_enable(SI5351_CLK0, 1);
        digitalWrite(PIN_PTT_OUT, HIGH);

        uint8_t seconds = 5;
        if (byTemp == 'T') seconds = 30;    //long test
        //Set to plenty of time so that the analyzer can get a fine reading on it
        for (uint8_t i=0; i<seconds; i++) {
          Serial.print(F("."));
          delay(1000);
          wdt_reset();
        }
        Serial.println("");
        si5351.output_enable(SI5351_CLK0, 0);
        digitalWrite(PIN_PTT_OUT, LOW);
      }

      //Send a WSPR packet. Lower case 'p' send either a type 1 or type 2 on the primary frequency, upper case 'P' transmits on the secondary frequency
      if (byTemp == 'p' || byTemp == 'P') {
        //Send a test packet
        Serial.println(F("Test Packet"));
        if (Config.getWSPRMessageType() & 0x01) {
          // Type 1 message
          buildWSPRSymbols(1);
        }
        else if (Config.getWSPRMessageType() & 0x02) {
          // Type 2 message
          buildWSPRSymbols(2);
        }
        sendWSPR((byTemp == 'p'));    //Use the primary frequency for 'p' and the secondary frequency for 'P'
      }

      //Quit out of configuration mode and reboot the system
      if (byTemp == 'q') {
        //Quit
        reboot();    //reboot the system  
      }

      if (byTemp == 'W' || byTemp == 'w') {
        //take the incoming configs and load them into the Config UDT

        Serial.println(F("Config mode..."));    //NOTE: This wording is critical for the ptConfigurator to know that we're in config mode

        if (Config.getConfigFromPC()) {
          Serial.println(F(" loaded"));

          Config.writeEEPROM();
          Serial.println(F(" saved"));

          Tracker.annunciate('w');
        } else {
          //something failed during the read of the config data
          Serial.println(F(" failed"));
        }

        reboot();    //reboot the system to apply the new configuration
      }

      Serial.println("");
      Serial.print(F(("Corr: ")));
      Serial.println(Config.getCorrection());
      Serial.print(CONFIG_PROMPT);
      ulUntil = millis() + CONFIG_TIMEOUT;    //reset the timer for the config mode
    }
  }
  
  reboot();    //reboot the system if we get here - this is the only way out of the endless loop  
}


/**
 * @brief reboot - This function reboots the system by resetting the ATmega328P microcontroller.
 * @return void
 */
void reboot() {
  //Reboot the system
  Serial.println(F("Rebooting..."));
  delay(1000);
  Tracker.reboot();
}

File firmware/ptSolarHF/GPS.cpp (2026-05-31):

/*
GPS Data Parser for Project: Traveler Flight Controllers
Copywrite 2011-2026 - Zack Clobes (W0ZC), Custom Digital Services, LLC

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
You should have received a copy of the GNU General Public License along with this program.  If not, see <http://www.gnu.org/licenses/>.

Version History:
Version 2.2.1 - April 11, 2026 - Fixed issue with Korean RF blackout.
Version 2.2.0 - January 26, 2026 - Functionality added to support WSPR mode.
                  * Added function to calculate Maidenhead grid square from latitude and longitude. 
				  * Changed time to uint8_t, and set 99 as invalid. 
				  * Added iLatitude/iLongitudeMicroDeg functions to get lat/lon in microdegrees.
				  * Reworked forbidden transmit zones.
Version 2.1.1 - September 25, 2025 - Removed UK from the prohibited transmit areas.
Version 2.1.0 - July 12, 2025 - Removed support for older uBlox GPS. Fixed bug where GPS was returning excessive precision. Eliminated validateGPSEntence() function.
Version 2.0.0 - May 9, 2025 - Major rewrite to be more object oriented. Added support for ATGM332 GPS module.
Version 1.0.4 - October 18, 2015 - Found bug where GPS latitude and longitude were exceeding the buffer.  Corrected and cleaned up some old code.
Version 1.0.3 - October 7, 2015 - Eliminated excess Serial.print's.  Cleaned up old comments.
Version 1.0.2 - April 27, 2015 - Added the possibility to capture GNGGA and GNRMC strings (instead of just GP***).
Version 1.0.1 - February 27, 2015 - Added initialization to the private member variables.  Cleaned up some old comments.
Version 1.0.0 - January 15, 2015 - Finalized the basic configuration and licensed GPS under the GPL3 license.


*/

#include "GPS.h"
#include <SoftwareSerial.h>


//Public Methods
GPS::GPS(uint8_t pinGPSRx, uint8_t pinGPSTx, uint8_t pinGPSEnable) {
	//Initializer
	this->_pinGPSRx = pinGPSRx;
	this->_pinGPSTx = pinGPSTx;
	this->_pinGPSEnable = pinGPSEnable;

	//Configure the Enable pin, if there's an enable pin defined as non-zero.
	this->disableGPS();    //disable the GPS module

	//Constructor - initialize the vars
	this->_szTemp[0] = 0;
	this->_iTempPtr = 0;
	this->_bFoundStart = false;
	this->_bRMCComplete = false;
	this->_bGGAComplete = false;  

	strcpy(this->_szLatitude, "1234.5678");
	strcpy(this->_szLongitude, "12345.6789");
	strcpy(this->_szGPSDate, "000000"); 
	this->_currTime.hh =_currTime.mm = _currTime.ss = 0;
	this->_cLatitudeHemi = 'N';
	this->_cLongitudeHemi = 'W';
	this->_iFixQuality = 0;
	this->_bFixValid = false;
	this->_iNumSats = 0;
	this->_fAltitude = 0.0;
	this->_fKnots = 0.0;
	this->_fCourse = 0.0;

	this->_lastDecodedMillis = millis();
	this->_outputNEMA = false;
}


/**
 * @brief  Initializes the GPS module and sets it to high altitude mode.
 * @note   The purpose of this function varies depending on which type of GPS module is being init'ed.
 */
void GPS::initGPS() {
	bool bSuccess = false;

	
	SoftwareSerial* GPS = nullptr;
	GPS = new SoftwareSerial(this->_pinGPSRx, this->_pinGPSTx, false);
	GPS->begin(9600);
	delay(500);

	/*
	// UBlox GPS - set the GPS to high altitude mode (Dynamic Model 6 – Airborne < 1g)
	if (this->_GPSType == 1) {
		if (this->_debugLevel > 0) Serial.println(F("Init UBlox"));


		const byte setdm6[] = {0xB5, 0x62, 0x06, 0x24, 0x24, 0x00, 0xFF, 0xFF, 0x06, 0x03, 0x00, 0x00, 0x00, 0x00, 0x10, 0x27, 0x00, 0x00,
			0x05, 0x00, 0xFA, 0x00, 0xFA, 0x00, 0x64, 0x00, 0x2C, 0x01, 0x00, 0x00, 0x00, 0x00, 0x00, 0x00, 0x00, 0x00,
			0x00, 0x00, 0x00, 0x00, 0x00, 0x00, 0x16, 0xDC };

		byte ackByteID = 0;
		byte ackPacket[10];
		
		
		//calculate a response checksum to verify that the config was sent correct.
		// Construct the expected ACK packet
		ackPacket[0] = 0xB5; // header
		ackPacket[1] = 0x62; // header
		ackPacket[2] = 0x05; // class
		ackPacket[3] = 0x01; // id
		ackPacket[4] = 0x02; // length
		ackPacket[5] = 0x00;
		ackPacket[6] = setdm6[2]; // ACK class
		ackPacket[7] = setdm6[3]; // ACK id
		ackPacket[8] = 0; // CK_A
		ackPacket[9] = 0; // CK_B
		
		// Calculate the checksums
		for (byte i=2; i<8; i++) {
			ackPacket[8] = ackPacket[8] + ackPacket[i];
			ackPacket[9] = ackPacket[9] + ackPacket[8];
		}
		
		//send the config to the GPS
		GPS->flush();
		GPS->write(0xFF);
		delay(500);
		
		for (byte i=0; i<44; i++) {
			GPS->write(setdm6[i]);
		}
		
		//keep track of how long we can listen to the GPS
		unsigned long ulUntil = millis() + 3000;
		
		while (millis() < ulUntil ) {
			// Test for success
			if (ackByteID > 9) return true;    //we had all 9 bytes come back through - valid response!!!
		
			// Make sure data is available to read
			if (GPS->available()) {
				byte c = GPS->read();
			
				// Check that bytes arrive in sequence as per expected ACK packet
				if (c == ackPacket[ackByteID]) {
					ackByteID++;
				} else {
					ackByteID = 0; // Reset and look again, invalid order
				}
			}
		}
	}
	*/

	// ATGM332D GPS - set the GPS to high altitude mode and disable unnecessary NMEA sentences
	if (this->_debugLevel > 0) Serial.println(F("Init ATGM332"));

	if (this->_debugLevel > 0) Serial.println(F("Config GGA/RMC"));
	GPS->println(F("$PCAS03,1,0,0,0,1,0,0,0,0*1E")); // turns on only $GNGGA and $GNRMC (1 sec)
	delay(100);

	if (this->_debugLevel > 1) Serial.println(F("Enable air"));
	GPS->println(F("$PCAS11,5*18")); // Airborne mode on ATM336H-5N GPS??
	delay(100);		
	

	
	
	// Clean up
	GPS->end();	//close the serial port to the GPS so it doens't draw excess current
	delete GPS;
	GPS = nullptr;

	pinMode(this->_pinGPSTx, INPUT);	//set the GPS Tx pin back to input mode so it doesn't draw excess current
	pinMode(this->_pinGPSRx, INPUT);	//set the GPS Rx pin back to input mode so it doesn't draw excess current
}
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

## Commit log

2026-01-25 Testing wspr_enc.c
    [ptSolarHF.kicad_sch]
2026-01-25 Back to a semi-working ptSolarHF. Still rebooting on 5351.
    [ptSolarHF.ino]
2026-01-26 Tweaks to proof of concept. Updates to Schematics.
    [ptSolarHF.kicad_pcb, ptSolarHF.kicad_sch]
2026-01-27 3D prints for carrier and neck attachment.
    [Balloon Neck Hanger.FCStd, Balloon Neck Hanger.stl, PCB Hook.FCStd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]
2026-01-27 Minor changes to 3D prints
    [Balloon Neck Hanger.FCStd, ptSolar Carrier.FCStd]
2026-02-02 Minor tweaks to arrive at 1.0
    [ptSolar Carrier.FCStd, ptSolar Carrier.stl]
2026-02-05 1.0 RC2 to fix issues with the GPS loosing lock between Type 2 and 3 packets.
    [GPS.cpp, ptSolarHF.ino]
2026-02-06 Updated converter script to support multiple balloons, and maintain persistence between restarts. Prototype new rib design for mounting supports.
    [Angled Carrier.FCStd, Rib.stl, Spar.stl]
2026-02-15 Firmware 1.0 RC3. Updates to the 3d carriers,
    [Angled Carrier.FCStd, Balloon Neck Hanger.FCStd, Balloon Neck Hanger.stl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]
2026-02-25 Implementing fine altitude modulation.
    [ptSolarHF.kicad_sch]
2026-02-28 Finalizing PCB v1.0.1
    [Angled Carrier.FCStd, Bill of Materials.csv, Rib.stl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]
2026-03-01 Added Configuration board to project
    [Bill of Materials.csv, breakout.kicad_sch, ptSolar-Config.kicad_pcb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]
2026-04-21 Updated to firmware 1.0.1
    [ptSolar-Config.kicad_pcb, ptSolar-Config.kicad_sch]
2026-04-26 Moved configuration cable into separate ptConfig project.
    [Angled Carrier.FCStd, Bill of Materials.csv, breakout.kicad_sch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]
2026-04-29 Tweaks to convert.py to track total flight time.
2026-05-31 Limiting GPS debug noise. Updates to converter to include position logging and KML file creation.
    [PCB Hook.FCStd, PCB Hook.stl, ptSolar Carrier.FCStd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]
2026-06-10 Fix for Converter.py logging, and updateding to firmware 1.0.2 to not disable the GPS during transmission.
    [ptSolarHF.ino]
2026-06-29 Reverting changes from 1.0.2 to disable GPS during xmit.
    [ptSolarHF.ino]

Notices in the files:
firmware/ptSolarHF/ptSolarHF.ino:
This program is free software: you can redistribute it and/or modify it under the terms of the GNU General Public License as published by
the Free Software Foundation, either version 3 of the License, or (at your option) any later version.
